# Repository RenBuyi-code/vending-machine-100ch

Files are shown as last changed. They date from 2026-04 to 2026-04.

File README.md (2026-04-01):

# Vending Machine 100-Channel Motor Driver

[!\[License\](https://img.shields.io/badge/License-Apache%202.0-blue.svg null)](LICENSE)

An open-source **100-channel vending machine motor driver control system** based on the **SWM181** microcontroller. Supports multiple motor types including spring motors, electromagnetic locks, and crawler-type motors, with RS485 communication protocol.

***

## Table of Contents

- [Overview](#overview)
- [Features](#features)
- [Hardware Architecture](#hardware-architecture)
- [Communication Protocol](#communication-protocol)
- [Project Structure](#project-structure)
- [Getting Started](#getting-started)
- [Default Configuration](#default-configuration)
- [License](#license)

***

## Overview

This project provides a complete firmware solution for controlling up to 100 motors in a vending machine setup. It uses a 10x10 matrix configuration to drive various types of motors commonly found in vending machines, including spring-based dispensers, electromagnetic locks, and crawler-type mechanisms.

The system is built around the Synwit SWM181 microcontroller (ARM Cortex-M0 core) and communicates via RS485 protocol, making it suitable for industrial vending machine applications.

***

## Features

### Motor Control

- **100-channel matrix control** (10x10 matrix, supporting up to 100 motors)
- **Multiple motor type support**:
  - Spring motors with feedback (FB Motor)
  - Electromagnetic locks with feedback (FB Electromagnet)
  - Electromagnetic locks without feedback (NFB Electromagnet)
  - Crawler-type motors with feedback (FB Crawler)

### Communication & Safety

- **RS485 communication** with dual-channel support
- **Infrared detection** for anti-pinch and goods detection
- **CRC16 checksum** for reliable communication
- **Watchdog timer** support for system stability

### Monitoring & Updates

- **Ambient monitoring** (temperature & humidity via Modbus RTU)
- **Electronic lock control**
- **XMODEM protocol** support for firmware updates

***

## Hardware Architecture

| Component | Description |
| --- | --- |
| MCU | SWM181 (ARM Cortex-M0, 48MHz) |
| Communication | RS485 (Dual Channel) |
| Motor Drive | 10x10 Matrix (X-Y control) |
| Feedback | 10-channel position feedback  |
| Sensors | Infrared detection (NPN type) |
| Power | 12V/24V DC |
| Debug | SWD/J-Link support |

### Matrix Configuration

- **X Axis (Columns)**: 10 channels for motor selection
- **Y Axis (Rows)**: 10 channels for motor activation
- **Feedback**: 10 channels for position sensing

***

## Communication Protocol

The system uses a custom frame protocol over RS485 with CRC16 error checking.

### Frame Structure

```
+------------+-------------+----------------+------+------+-----------+----------+
| Frame Head | Device Type | Device Address | CMD  | Data | CRC16     | Frame End|
| 0xDDCCBBAA | 1 byte      | 1 byte         | 1 byte| var | 2 bytes   |0xFBFCFDFE|
| (4 bytes)  |             |                |      |      |           | (4 bytes)|
+------------+-------------+----------------+------+------+-----------+----------+
```

### Supported Commands

| Command | Value  | Description |
| --- | --- | --- |
| CMD\_OUTPUT | `0x01` | Control motor to dispense goods |
| CMD\_READ | `0x02` | Read temperature, humidity, lock status |
| CMD\_LOCK | `0x03` | Control electronic lock |
| CMD\_REPLY | `0x04` | Response frame |
| CMD\_MODIFICATION | `0x05` | Modify device RS485 address |

### Response Codes

| Code | Value  | Description |
| --- | --- | --- |
| RESULT\_VM\_FB\_MOTOR\_OUTPUT | `0xC1` | Motor output result |
| RESULT\_VM\_STATES | `0xC2` | Status query result |
| RESULT\_VM\_ADDR\_MODIFICATION | `0xC3` | Address modification result |
| RESULT\_VM\_LOCK | `0xC4` | Lock control result |
| RESULT\_VM\_OUTPUT\_NFB\_ELECTROMAGNET | `0xC5` | NFB electromagnet result |
| RESULT\_VM\_OUTPUT\_FB\_ELECTROMAGNET  | `0xC6` | FB electromagnet result |

***

## Project Structure

```
vending-machine-100ch/
├── Code/
│   └── spring_drive_V1.6/          # Firmware source code (Keil MDK project)
│       ├── Application/             # Application layer
│       │   ├── main.c               # Main entry point
│       │   ├── vm.c / vm.h          # Vending machine logic & protocol
│       │   ├── ambient.c / ambient.h# Temperature & humidity monitoring
│       │   ├── xmodem.c / xmodem.h  # Firmware update protocol
│       │   ├── soft_timer.c/h       # Software timer implementation
│       │   ├── Drivers/             # Hardware drivers
│       │   │   └── Source/
│       │   │       ├── motor_driver.c   # Motor control (10x10 matrix)
│       │   │       ├── rs485.c          # RS485 communication driver
│       │   │       ├── infrared_ray_check.c  # IR sensor detection
│       │   │       ├── lock.c           # Electronic lock control
│       │   │       ├── led.c            # LED indicator control
│       │   │       ├── timer.c          # Hardware timer
│       │   │       ├── tick.c           # System tick
│       │   │       ├── uart.c           # UART driver
│       │   │       ├── address.c        # Device address management
│       │   │       └── flash.c          # Flash storage
│       │   ├── SEEGER/              # SEGGER RTT debug
│       │   └── MALLOC/              # Memory allocator
│       └── Project/                 # Keil project files
│           ├── spring.uvprojx       # Keil project
│           └── RTE/                 # Runtime environment
│
├── HW/
│   └── 弹簧货道电机驱动板V0816/      # Hardware design files
│       ├── SCH/                     # Schematics (Altium Designer)
│       ├── PCB/                     # PCB layout
│       ├── Project/                 # Altium project files
│       ├── Libraries/               # Component libraries
│       ├── Datasheet/               # Component datasheets
│       │   ├── 主控/                # MCU datasheet (SWM181)
│       │   └── 通信IC/              # Communication IC datasheets
│       └── Output/                  # Manufacturing outputs
│
└── LICENSE                          # Apache 2.0 License
```

***

## Getting Started

### Hardware Requirements

- **Vending machine motor driver board** (弹簧货道电机驱动板 V0816)
- **Power supply**: 12V/24V DC (depending on motor specifications)
- **RS485 master controller** (for communication)
- **Motors**: Spring motors, electromagnetic locks, or crawler-type motors
- **Debugger**: J-Link or compatible SWD debugger

### Software Requirements

- **Keil MDK-ARM** (version 5.0 or later recommended)
- **J-Link Software** (for debugging and flashing)
- **Serial terminal** (for RS485 communication testing)

### Build Instructions

1. **Open the project**:
   ```
   Code/spring_drive_V1.6/Project/spring.uvprojx
   ```
2. **Select target device**: SWM181xC or SWM181xB
3. **Build the project**:
   - Click `Build` button or press `F7`
4. **Connect debugger**:
   - Connect J-Link to the SWD interface on the board
5. **Flash firmware**:
   - Click `Download` button or press `F8`

### Communication Test

1. Connect RS485 to your master controller
2. Set baudrate to 115200
3. Send test frame:
   ```
   Frame Head: AA BB CC DD
   Device Type: 01
   Device Address: 01
   CMD: 02 (Read Status)
   Data: 00 00 00 00 00 00 00
   CRC16: [calculated]
   Frame End: FE FD FC FB
   ```

***

## Default Configuration

| Parameter | Default Value | Description |
| --- | --- | --- |
| RS485 Address | `0x01` | Device address (modifiable via CMD 0x05) |
| Broadcast Address | `0xFF` | Broadcast address for all devices |
| Baudrate | 115200 | RS485 communication speed |
| Device Type | `0x01` | Motor driver device type |
| Frame Head | `0xDDCCBBAA`  | Protocol frame header |
| Frame End | `0xFBFCFDFE`  | Protocol frame footer |
| Watchdog | Enabled | System watchdog timer |
| Max Channels | 100 | Maximum motor channels (10x10) |

***

## License

This project is licensed under the **Apache License 2.0**.

See [LICENSE](LICENSE) file for details.

***

## Notes

- X and Y axis mapping follows the schematic design
- Infrared sensor uses NPN signal type
- Motor feedback signals are active-low
- Ensure proper power supply current rating for all connected motors

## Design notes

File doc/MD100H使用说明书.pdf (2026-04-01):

# MD100H使用说明书

1 / 22

目录

2 / 22

3 / 22

1.版本修订

2019-2-25 全新修订 RBY

2.产品概览

- 矩阵式电路结构
- 支持100通道的电机驱动
- 支持最多255块控制卡并联扩展
- 增强型灵活通讯口，板载一路RS232,两路RS485，两路TTL其中一路复用给
RS232,RS485。
- 带一路N-MOS开关量输出可接机柜锁
- 温湿度采样，支持RS485接口的传感器级联

3.电气特性

供电电压：DC24V （12V可选）
静态电流： 小于20mA
驱动电流：最大3A
通讯接口：RS485,RS232,TTL_UART

4 / 22

## 3.1安装尺寸（mm）

X孔距115mm
Y孔距80mm
板长 124.714
板宽 88.138mm

5 / 22

4.接线方式

4.1电源接线方式

供电电压24V，12V可选
静态电流 小于40mA

最大电流取决于负载电流。

## 4.2锁接线方式

注意板子由12V供电时机柜锁7812无法输出12V，但与电源共地仍能完成锁控制 Y为输出，Y截至时为高阻态，Y导通时接地
IN用于接入机柜锁反馈线，电压不可高于3.3V。默认为3.3V，将其拉低则门状态改变。

6 / 22

4.2电机或电磁锁接线方式

X接负载正，Y接负载负，IN接负载反馈

7 / 22

4.3光栅接线方式

光幕接口 信号 V1，GND，IN V1给光幕供电，GND是电源地线，IN光栅信号 待机时，IN需要高阻抗或者0V，检测道商品掉落时为5V。

## 4.4主通信接口

2R : RS232 RX
2T : RS232 TX
UR: UART RXD
UT: UART TXD
A1: RS485 A
B1: RS485B
此通信接口用于控制整个板卡，以上3路接口不可同时使用

8 / 22

4.5传感器通信接口

5V:接传感器+
0V:接传感器-
A2: RS485 A
B2: RS485 B

# 6.通信参数

通讯参数： 9600bps，1停止位，无奇偶校验，无流量控制

在通讯过程中，上位机（安卓或者PC，称为主机）与控制卡（称为从机）采用主从方

式
1) 每次通讯由主机发起请求，从机应答
2) 主机收到上次请求的应答 或者超时后才可以发起新的请求
3) 在一个通讯网络中可包含一台主机和若干台从机
4) 地址0XFF作为广播地址。只用作从机地址修改。

通讯流程如下：
1. 主机下发指令
2. 等待50ms
3. 接收从机响应(超时8秒)

9 / 22

6.1通信格式 上位机 → 下位机

协议格式 ，PC Android或Linux主板为上位机，板卡为下位机
帧起始域(Feame Start) | 4byte
设备类型（Device_Type） | 1byte
地址域（Address） | 1byte
功能码(Funtion Code) | 1byte
数据域(Date) | 5byte
差错校验(CRC16) | 2byte
帧结束域(Feame End) | 4byte

通讯协议中使用的数据帧，一帧指令或响应的长度为18字节（数据域不足5个补0），

包含了帧头、设备类型、地址、指令、数据段、帧尾及校验码七部分。
帧起始域 | AAH | BBH | CCH | DDH
帧结束域 | FEH | FDH | FCH | FBH
设备类型 | 01H-FFH | 电机驱动板01H
地址域（普通地址） | 01H - FEH | 默认为01H
地址域（广播地址） | FFH
功能码 | 值 | 备注
CMD_OUTPUT | 01H | 驱动负载
CMD_READ | 02H | 读传感器值，以及锁状态
CMD_LOCK | 03H | 操作机柜锁
CMD_REPLY | 04H | 回复
CMD_MODIFICATION_ADDRES S | 05H | 修改地址

10 / 22

## 6.2 CMD_OUTPUT 数据域

名称 | 位 | 类型 | 数据类型 | 描述
load_number | Byte1 | R/W | uint8_t | 负载编号，取值01H-64H
load_flag | Byte2 | R | uint8_t | 负载标志 下位机->上位机: 正常：01H 错误：EEH 超时：00H
ir_flag | Byte3 | R/W | uint8_t | 红外标志位 上位机->下位机: 使能掉货检测：FFH 失能掉货检测：EFH 下位机->上位机： 正常：01H 错误：EEH 超时：00H
load_type | Byte4 | W | uint8_t | 负载类型: 有反馈弹簧电机：00H 有反馈电磁锁：01H 无反馈电磁锁：02H 有反馈履带电机：0x03
timer_value | Byte5 | W | uint8_t | 超时定时器单位为秒

## 6.3 CMD_READ 数据域

上位机->下位机，数据域全部补0。

## 6.4 CMD_LOCK 数据域

名称 | 类型 | 数据类型 | 描述
states | R/W | uint8_t | 0x01锁负极接地， 0x00锁负极高阻

11 / 22

## 6.5 CMD_REPLY 数据域

上位机->下位机此域无效

## 6.6 CMD_MODIFICATION_ADDRESS 数据域

名称 | 类型 | 数据类型 | 描述
new_address | R/W | uint8_t | 取值为00H-FEH

默认地址为01H
7.通信格式 下位机 → 上位机

回复时功能码皆为04H，即CMD_REPLY

## 7.1 CMD_OUTPUT回复

数据域

名称 | 位 | 类型 | 数据类型 | 描述
load_number | 1 | R/W | uint8_t | 负载编号:01H-64H
load_flag | 2 | R/W | uint8_t | 正常 : 01H 超时 : 00H 出错 : EEH
ir_flag | 3 | R/W | uint8_t | 正常 : 01H 超时 : 00H 出错 : EEH

12 / 22

## 7.2 CMD_READ 回复

数据域
名称 | 位 | 类型 | 数据类型 | 描述
lock_states | 1 | R/W | uint8_t | 导通0xFF, 截至0x00
humidity | 2:3 | R/W | short | 湿度，小端字节序
temperature | 4:5 | R/W | short | 温度，小端字节序

操作锁，电机，查询修改地址都会有回复。

13 / 22

### 7.3 板卡通信例子

7.3.1控制板卡驱动负载，失能光栅。

上位机->下位机

例子：控制板卡地址01H和01H号负载，不检测光栅。
AA BB CC DD 01 01 01 01 00 EF 00 00 06 24 FE FD FC FB
AA BB CC DD 01 01 01 01 00 EF 00 00 06 24 FE FD FC FB
名称 | 字节域&描述 | 值
帧起始域 | 1 | AAH
| 2 | BBH
| 3 | CCH
| 4 | DDH
设备类型 | 5 | 01H
地址域 | 6 地址 | 01H
功能码 | 7 功能码 | 01H
数据域 | 8 负载编号 | 01H
| 9 负载标志 | 00H
| 10 光栅标志 | EFH
| 11 无效字节 | 00H
| 12 无效字节 | 00H
差错校验 CRC16_Modbus | 13 低位 | 06H
| 14 高位 | 24H
帧结束域 | 15 | FEH
| 16 | FDH
| 17 | FCH
| 18 | FBH

14 / 22

下位机->上位机

例子：不检测光栅EFH，负载标志01表示电机正常旋转一周。
AA BB CC DD 01 04 01 01 EF 00 00 11 B2 FE FD FC FB
名称 | 字节域&描述 | 值
帧起始域 | 1 | AAH
| 2 | BBH
| 3 | CCH
| 4 | DDH
设备类型 | 5 售货机类型 | 01H
地址域 | 6 地址 | 01H
功能码 | 7 功能码 | 04H
数据域 | 8 负载编号 | 01H
| 9 负载标志 | 01H
| 10 光栅标志 | EFH
| 11 无效 | 00H
| 12 无效 | 00H
差错校验 CRC16_Modbus | 13 低位 | 11H
| 14 高位 | B2H
帧结束域 | 15 | FEH
| 16 | FDH
| 17 | FCH
| 18 | FBH

15 / 22

7.3.2控制板卡驱动负载，使能光栅检测

上位机->下位机

例子：控制板卡地址01H和01H号负载，检测光栅。
AA BB CC DD 01 01 01 00 FF 00 00 07 E1 fe fd fc fb
名称 | 字节域&描述 | 值
帧起始域 | 1 | AAH
| 2 | BBH
| 3 | CCH
| 4 | DDH
设备类型 | 5 售货机类型 | 01H
地址域 | 6 地址 | 01H
功能码 | 7 功能码 | 01H
数据域 | 8 负载编号 | 01H
| 9 负载表示 | 00H
| 10 光栅标志 | FFH
| 11 无效 | 00H
| 12 无效 | 00H
差错校验 CRC16_Modbus | 13 低位 | 07H
| 14 高位 | E1H
帧结束域 | 15 | FEH
| 16 | FDH
| 17 | FCH
| 18 | FBH

16 / 22

下位机->上位机

例子：控制板卡地址01H和01H号负载，使能检测光栅。
AA BB CC DD 01 01 01 04 01 11 EE 00 00 01 72 FE FD FC FB
名称 | 字节域&描述 | 值
帧起始域 | 1 | AAH
| 2 | BBH
| 3 | CCH
| 4 | DDH
设备类型 | 5 售货机类型 | 01H
地址域 | 6 地址 | 01H
功能码 | 7 功能码 | 04H
数据域 | 8 负载编号 | 01H
| 9 负载表示 | 11H
| 10 光栅标志 | EEH
| 11 无效 | 00H
| 12 无效 | 00H
差错校验 CRC16_Modbus | 13 低位 | 01H
| 14 高位 | 72H
帧结束域 | 15 | FEH
| 16 | FDH
| 17 | FCH
| 18 | FBH

17 / 22

7.3.3查询温湿度传感器及锁状态

上位机->下位机

AA BB CC DD 01 01 02 00 00 00 00 00 0A 22 FE FD FC FB
名称 | 字节域&描述 | 值
帧起始域 | 1 | AAH
| 2 | BBH
| 3 | CCH
| 4 | DDH
设备类型 | 5 售货机类型 | 01H
地址域 | 6 地址 | 01H
功能码 | 7 功能码 | 02H
数据域 | 8 锁状态 | 00H
| 9 湿度低 | 00H
| 10 湿度高 | 00H
| 11 温度低 | 00H
| 12 温度高 | 00H
差错校验 CRC16_Modbus | 13 低位 | 0AH
| 14 高位 | 22H
帧结束域 | 15 | FEH
| 16 | FDH
| 17 | FCH
| 18 | FBH

18 / 22

下位机->上位机

名称 | 字节域&描述 | 值
帧起始域 | 1 | AAH
| 2 | BBH
| 3 | CCH
| 4 | DDH
设备类型 | 5 售货机类型 | 01H
地址域 | 6 地址 | 01H
功能码 | 7 功能码 | 02H
数据域 | 8 锁状态 | 00H
| 9 湿度低 | 00H
| 10 湿度高 | 00H
| 11 温度低 | 00H
| 12 温度高 | 00H
差错校验 CRC16_Modbus | 13 低位 | 0AH
| 14 高位 | 22H
帧结束域 | 15 | FEH
| 16 | FDH
| 17 | FCH
| 18 | FBH

AA BB CC DD 01 04 00 04 02 24 00 E6 FB FE FD FC FB
备注：锁闭合时，信号线导通Byte.7=00H,锁打开时Byte.7=01H，使用时注意电锁有无反馈

功能，反馈形式应为，锁闭合反馈线导通，锁打开是，反馈线开路。

19 / 22

### 7.3.4 控制板卡开关机柜锁

上位机->下位机

AA BB CC DD 01 03 01 00 00 00 00 36 33 FE FD FC FB

名称 | 字节域&描述 | 值
帧起始域 | Byte.1 | AAH
| Byte.2 | BBH
| Byte.3 | CCH
| Byte.4 | DDH
地址域 | Byte.5 地址 | 01H
功能码 | Byte.6 功能码 | 03H
数据域 | Byte.7 锁状态 | 00H
| Byte.8 湿度低 | 00H
| Byte.9 湿度高 | 00H
| Byte.10 温度低 | 00H
| Byte.11 温度高 | 00H
差错校验 CRC16_Modbus | Byte.12 低位 | 36H
| Byte.13 高位 | 33H
帧结束域 | Byte.14 | FEH
| Byte.15 | FDH
| Byte.16 | FCH
| Byte.17 | FBH
备注:
默认为开锁3S后，关闭锁，注意锁可以导通的时间。

下位机->上位机

与 7.3.3 下位机->上位机 相同

20 / 22

7.3.5修改板卡地址

上位机->下位机

AA BB CC DD 01 05 02 00 00 00 00 72 55 FE FD FC FB
名称 | 字节域&描述 | 值
帧起始域 | 1 | AAH
| 2 | BBH
| 3 | CCH
| 4 | DDH
设备类型 | 5 | 01H
地址域 | 5 地址 | 01H
功能码 | 6 功能码 | 05H
数据域 | 7 新地址 | 01H
| 8 无效 | 00H
| 9 无效 | 00H
| 10 无效 | 00H
| 11 无效 | 00H
差错校验 CRC16_Modbus | 12 低位 | 72H
| 13 高位 | 55H
帧结束域 | 14 | FEH
| 15 | FDH
| 16 | FCH
| 17 | FBH

备注：
此命令将板卡地址01H,改为02H,修改成功则会回复7.3.3下位机->上位机,注意板卡地址 会是否改为02H，如果是则修改成功。

21 / 22

### 8. 校验码计算

红字为参与校验的数据
帧起始域(Feame Start) | 4byte
设备类型（Device_Type） | 1byte
地址域（Address） | 1byte
功能码(Funtion Code) | 1byte
数据域(Date) | 5byte
差错校验(CRC16) | 2byte
帧结束域(Feame End) | 4byte
const uint8_t crctalbeabs[23] = { 0x7E, 0x01, 0x00, 0x00, 0x01, 0x10, 0x02, 0x00, 0x27, 0x00, 0x 0C, 0x00, 0x02, 0x00, 0x00, 0x00, 0x00, 0x00, 0x50, 0x00, 0x3C, 0x00, 0x03};
uint16_t crc16tablefast(uint8_t *ptr, uint16_t len)
{
unsigned char i;
unsigned short crc = 0xFFFF;
if (len == 0) {
len = 1;
}
while (len--) {
crc ^= *ptr;
for (i = 0; i<8; i++)
{
if (crc & 1) {
crc >>= 1;
crc ^= 0xA001;
} else {
crc >>= 1;
}
}
ptr++;
}
return crc;
}

备注：注意字节序问题

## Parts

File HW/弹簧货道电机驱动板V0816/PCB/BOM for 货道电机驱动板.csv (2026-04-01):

Comment | Description | Designator | Footprint | LibRef | Pins | Quantity
0R | 贴片电阻 | R25 | R 0603 | R | 2 | 1
100nF\NC | 贴片电容 | C12,C11,C10,C9,C8 | 0603_C | 0603 100nF (104) 10% 50V | 2 | 5
104 | 无极性贴片电容 | C3,C4,C2,C6,C1,C16,C13,C7 | C 0603 | C | 2 | 8
10K | 贴片电阻 | R24,R14,R9,R21,R11_U_SIG_IN10,R11_U_SIG_IN9,R11_U_SIG_IN8,R11_U_SIG_IN7,R11_U_SIG_IN6,R11_U_SIG_IN5,R11_U_SIG_IN4,R11_U_SIG_IN3,R11_U_SIG_IN2,R11_U_SIG_IN1,R7_U_Drive_Y10,R7_U_Drive_Y9,R7_U_Drive_Y8,R7_U_Drive_Y7,R7_U_Drive_Y6,R7_U_Drive_Y5,R7_U_Drive_Y4,R7_U_Drive_Y3,R7_U_Drive_Y2,R7_U_Drive_Y1,R4_U_Drive_X10,R4_U_Drive_X9,R4_U_Drive_X8,R4_U_Drive_X7,R4_U_Drive_X6,R4_U_Drive_X5,R4_U_Drive_X4,R4_U_Drive_X3,R4_U_Drive_X2,R4_U_Drive_X1,R1_U_Drive_X10,R1_U_Drive_X9,R1_U_Drive_X8,R1_U_Drive_X7,R1_U_Drive_X6,R1_U_Drive_X5,R1_U_Drive_X4,R1_U_Drive_X3,R1_U_Drive_X2,R1_U_Drive_X1 | R 0603 | R | 2 | 44
10k | 贴片电阻 | R5_U_Drive_Y10,R5_U_Drive_Y9,R5_U_Drive_Y8,R5_U_Drive_Y7,R5_U_Drive_Y6,R5_U_Drive_Y5,R5_U_Drive_Y4,R5_U_Drive_Y3,R5_U_Drive_Y2,R5_U_Drive_Y1 | R 0603 | R | 2 | 10
10uF/35V | 贴片电解电容 | E3,E4 | CM B(4*5.4) | C-CM | 2 | 2
120Ω | 贴片电阻 | R15 | 0603_R | 0603 120Ω (1200) 1% | 2 | 1
15K | 贴片电阻 | R17,R2_U_Drive_X10,R2_U_Drive_X9,R2_U_Drive_X8,R2_U_Drive_X7,R2_U_Drive_X6,R2_U_Drive_X5,R2_U_Drive_X4,R2_U_Drive_X3,R2_U_Drive_X2,R2_U_Drive_X1 | R 0603 | R | 2 | 11
1K | 贴片电阻 | R23,R22,R20,R6_U_Drive_Y10,R6_U_Drive_Y9,R6_U_Drive_Y8,R6_U_Drive_Y7,R6_U_Drive_Y6,R6_U_Drive_Y5,R6_U_Drive_Y4,R6_U_Drive_Y3,R6_U_Drive_Y2,R6_U_Drive_Y1,R3_U_Drive_X10,R3_U_Drive_X9,R3_U_Drive_X8,R3_U_Drive_X7,R3_U_Drive_X6,R3_U_Drive_X5,R3_U_Drive_X4,R3_U_Drive_X3,R3_U_Drive_X2,R3_U_Drive_X1 | R 0603 | R | 2 | 23
20pF | 无极性贴片电容 | C14,C5 | C 0603 | C | 2 | 2
220uF/35V | 贴片电解电容 | E6,E2 | CM E(8*10.2) | C-CM | 2 | 2
24MHz | 2脚晶振 | X1 | XTAL-49S SMD | XTAL-2 | 2 | 1
4.7K | 贴片电阻 | R8,R19,R12,R16,R18,R13,R10_U_SIG_IN10,R10_U_SIG_IN9,R10_U_SIG_IN8,R10_U_SIG_IN7,R10_U_SIG_IN6,R10_U_SIG_IN5,R10_U_SIG_IN4,R10_U_SIG_IN3,R10_U_SIG_IN2,R10_U_SIG_IN1 | R 0603 | R | 2 | 16
47uF/6.3V | 贴片电解电容 | E5 | CM C(5*5.4) | C-CM | 2 | 1
680uF/6.3V | 贴片电解电容 | E1 | CM E(8*10.2) | C-CM | 2 | 1
68uH 2A | INDUCTOR | L1 | CDRH74 | INDUCTOR | 2 | 1
78Mxx | 线性稳压芯片 | V1 | LC-TO-252-2 | 78Mxx | 3 | 1
AMS1117-3.3 | 低压差线性稳压(LDO) | VR1 | SOT-223 | SOT-223 AMS1117-3.3 | 4 | 1
CJ2307 | P沟道场效应管 | Q8 | SOT23 | P-MOS | 3 | 1
CJA03N10 | N沟道场效应管 | Q6 | LC-SOT-89(SOT-89-3) | CJA03N10 | 4 | 1
HD30N03 | N沟道场效应管 | Q4_U_Drive_Y10,Q4_U_Drive_Y9,Q4_U_Drive_Y8,Q4_U_Drive_Y7,Q4_U_Drive_Y6,Q4_U_Drive_Y5,Q4_U_Drive_Y4,Q4_U_Drive_Y3,Q4_U_Drive_Y2,Q4_U_Drive_Y1 | TO252 | N-MOS | 3 | 10
HDR-1X2 | 2P接插件 | JP11 | HDR-1X2 | Header 2 | 2 | 1
HDR-1X4 | 4P接插件 | JP6 | HDR-1X4 | Header 4 | 4 | 1
HDR-1X4 | 4P接插件 | JP9 | XH2.54-4P | Header 4 | 4 | 1
S8050 | NPN三极管 | Q9,Q7,Q5_U_SIG_IN10,Q5_U_SIG_IN9,Q5_U_SIG_IN8,Q5_U_SIG_IN7,Q5_U_SIG_IN6,Q5_U_SIG_IN5,Q5_U_SIG_IN4,Q5_U_SIG_IN3,Q5_U_SIG_IN2,Q5_U_SIG_IN1,Q3_U_Drive_Y10,Q3_U_Drive_Y9,Q3_U_Drive_Y8,Q3_U_Drive_Y7,Q3_U_Drive_Y6,Q3_U_Drive_Y5,Q3_U_Drive_Y4,Q3_U_Drive_Y3,Q3_U_Drive_Y2,Q3_U_Drive_Y1,Q2_U_Drive_X10,Q2_U_Drive_X9,Q2_U_Drive_X8,Q2_U_Drive_X7,Q2_U_Drive_X6,Q2_U_Drive_X5,Q2_U_Drive_X4,Q2_U_Drive_X3,Q2_U_Drive_X2,Q2_U_Drive_X1 | SOT-23 | NPN | 3 | 32
SE20P03 | P沟道场效应管 | Q1_U_Drive_X10,Q1_U_Drive_X9,Q1_U_Drive_X8,Q1_U_Drive_X7,Q1_U_Drive_X6,Q1_U_Drive_X5,Q1_U_Drive_X4,Q1_U_Drive_X3,Q1_U_Drive_X2,Q1_U_Drive_X1 | TO252 | P-MOS | 3 | 10
SMAJ6.5CA | TVS | D6,D8,D10,D5 | SMA(DO-214AC)_S1 | SMB/DO-214AA P6SMB6.8CA | 2 | 4
SMBJ30CA | TVS | D9,D2 | LC-SMA(DO-214AC)_S1 | SMB/DO-214AA P6SMB6.8CA | 2 | 2
SS34 | 二极管 | D3,D7,D4,D1 | SMA(DO-214AC)_S1 | SMA(DO-214AC) SS54 | 2 | 4
SWM181RCT6-50 | 微控制器, Cortex-M0系列, AA-00 | U1 | LC-LQFP-64_10x10x05P | SWM181RCT6-50 | 64 | 1
TLC-NSMD005 | 贴片保险丝 | F3,F2 | FU 1206 | FU | 2 | 2
TRB300 | 直插保险丝 | F1 | 5.08mm | FU | 2 | 1
UT3232G-S16-R | RS232 | U4 | SOIC-16_150mil | MAX232ESE | 16 | 1
XH2.54-10P | 10P接插件 | JP3,JP2 | XH2.54-10P | Header 10 | 10 | 2
XH2.54-11P | 11P接插件 | JP5 | XH2.54-11P | Header 11 | 11 | 1
XH-2.54-4P | 4P接插件 | JP10,JP8,JP4,JP1 | XH2.54-4P | Header 4 | 4 | 4
XH-2.54-8P | 8P接插件 | JP7 | XH2.54-8P | Header 8 | 8 | 1
XL1509-5E1 | DC-DC芯片 | U2 | SOP-8_150mil | XL1509-3.3E1 | 8 | 1
YD3082E | RS-485/RS-422 | U5,U3 | SOIC-8_150mil | SP485EEN-L/TR | 8 | 2
红色 | 贴片LED | LED1 | LED 0603G | LED-SMD | 2 | 1

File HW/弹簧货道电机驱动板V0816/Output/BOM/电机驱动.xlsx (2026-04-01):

Comment | Description | Designator | Footprint | Pins | Quantity
24MHz | 2脚晶振 | X1 | XTAL-49S SMD | 2 | 1
XL1509-5E1 | DC-DC芯片 | U2 | SOP-8_150mil | 8 | 1
SWM181RCT6-50 | 微控制器, Cortex-M0系列, AA-00 | U1 | LC-LQFP-64_10x10x05P | 64 | 1
AMS1117-3.3 | 低压差线性稳压(LDO) | VR1 | SOT-223 | 3 | 1
SMAJ3.3A | TVS | D11 | LC-SMA(DO-214AC)_S1 | 2 | 1
SMAJ6.5CA | TVS | D5, D6, D8, D10 | SMA(DO-214AC)_S1 | 2 | 4
SMBJ30CA | TVS | D2, D9 | LC-SMA(DO-214AC)_S1 | 2 | 2
SS34 | 二极管 | D1, D3, D4, D7 | SMA(DO-214AC)_S1 | 2 | 4
1K | 贴片电阻 | R3_U_Drive_X1, R3_U_Drive_X2, R3_U_Drive_X3, R3_U_Drive_X4, R3_U_Drive_X5, R3_U_Drive_X6, R3_U_Drive_X7, R3_U_Drive_X8, R3_U_Drive_X9, R3_U_Drive_X10, R6_U_Drive_Y1, R6_U_Drive_Y2, R6_U_Drive_Y3, R6_U_Drive_Y4, R6_U_Drive_Y5, R6_U_Drive_Y6, R6_U_Drive_Y7, R6_U_Drive_Y8, R6_U_Drive_Y9, R6_U_Drive_Y10, R20, R22 | R 0603 | 2 | 22
4.7K | 贴片电阻 | R8, R9, R10_U_SIG_IN1, R10_U_SIG_IN2, R10_U_SIG_IN3, R10_U_SIG_IN4, R10_U_SIG_IN5, R10_U_SIG_IN6, R10_U_SIG_IN7, R10_U_SIG_IN8, R10_U_SIG_IN9, R10_U_SIG_IN10, R12, R13, R16, R18, R19 | R 0603 | 2 | 17
10K | 贴片电阻 | R1_U_Drive_X1, R1_U_Drive_X2, R1_U_Drive_X3, R1_U_Drive_X4, R1_U_Drive_X5, R1_U_Drive_X6, R1_U_Drive_X7, R1_U_Drive_X8, R1_U_Drive_X9, R1_U_Drive_X10, R4_U_Drive_X1, R4_U_Drive_X2, R4_U_Drive_X3, R4_U_Drive_X4, R4_U_Drive_X5, R4_U_Drive_X6, R4_U_Drive_X7, R4_U_Drive_X8, R4_U_Drive_X9, R4_U_Drive_X10, R5_U_Drive_Y1, R5_U_Drive_Y2, R5_U_Drive_Y3, R5_U_Drive_Y4, R5_U_Drive_Y5, R5_U_Drive_Y6, R5_U_Drive_Y7, R5_U_Drive_Y8, R5_U_Drive_Y9, R5_U_Drive_Y10, R7_U_Drive_Y1, R7_U_Drive_Y2, R7_U_Drive_Y3, R7_U_Drive_Y4, R7_U_Drive_Y5, R7_U_Drive_Y6, R7_U_Drive_Y7, R7_U_Drive_Y8, R7_U_Drive_Y9, R7_U_Drive_Y10, R11_U_SIG_IN1, R11_U_SIG_IN2, R11_U_SIG_IN3, R11_U_SIG_IN4, R11_U_SIG_IN5, R11_U_SIG_IN6, R11_U_SIG_IN7, R11_U_SIG_IN8, R11_U_SIG_IN9, R11_U_SIG_IN10, R14, R17 | R 0603 | 2 | 52
15K | 贴片电阻 | R2_U_Drive_X1, R2_U_Drive_X2, R2_U_Drive_X3, R2_U_Drive_X4, R2_U_Drive_X5, R2_U_Drive_X6, R2_U_Drive_X7, R2_U_Drive_X8, R2_U_Drive_X9, R2_U_Drive_X10 | R 0603 | 2 | 10
100K | 贴片电阻 | R21 | R 0603 | 2 | 1
SE20P03 | P沟道场效应管 | Q1_U_Drive_X1, Q1_U_Drive_X2, Q1_U_Drive_X3, Q1_U_Drive_X4, Q1_U_Drive_X5, Q1_U_Drive_X6, Q1_U_Drive_X7, Q1_U_Drive_X8, Q1_U_Drive_X9, Q1_U_Drive_X10 | TO252 | 3 | 10
S8550 | NPN三极管 | Q2_U_Drive_X1, Q2_U_Drive_X2, Q2_U_Drive_X3, Q2_U_Drive_X4, Q2_U_Drive_X5, Q2_U_Drive_X6, Q2_U_Drive_X7, Q2_U_Drive_X8, Q2_U_Drive_X9, Q2_U_Drive_X10, Q3_U_Drive_Y1, Q3_U_Drive_Y2, Q3_U_Drive_Y3, Q3_U_Drive_Y4, Q3_U_Drive_Y5, Q3_U_Drive_Y6, Q3_U_Drive_Y7, Q3_U_Drive_Y8, Q3_U_Drive_Y9, Q3_U_Drive_Y10, Q5_U_SIG_IN1, Q5_U_SIG_IN2, Q5_U_SIG_IN3, Q5_U_SIG_IN4, Q5_U_SIG_IN5, Q5_U_SIG_IN6, Q5_U_SIG_IN7, Q5_U_SIG_IN8, Q5_U_SIG_IN9, Q5_U_SIG_IN10 | SOT-23 | 3 | 30
2N7002 | N沟道场效应管 | Q7 | SOT23 | 3 | 1
HD30N03 | N沟道场效应管 | Q4_U_Drive_Y1, Q4_U_Drive_Y2, Q4_U_Drive_Y3, Q4_U_Drive_Y4, Q4_U_Drive_Y5, Q4_U_Drive_Y6, Q4_U_Drive_Y7, Q4_U_Drive_Y8, Q4_U_Drive_Y9, Q4_U_Drive_Y10 | TO252 | 3 | 10
红色 | 贴片LED | LED1 | LED 0603G | 2 | 1
68uH 2A | INDUCTOR | L1 | CDRH74 | 2 | 1
XH2.54-11P | 11P接插件 | JP5 | XH2.54-11P | 11 | 1
XH2.54-10P | 10P接插件 | JP2, JP3 | XH2.54-10P | 10 | 2
XH-2.54-8P | 8P接插件 | JP7 | XH2.54-8P | 8 | 1
XH-2.54-5P | 5P接插件 | JP9 | XH2.54-5P | 5 | 1
HDR-1X4 | 4P接插件 | JP6 | HDR-1X4 | 4 | 1
XH-2.54-4P | 4P接插件 | JP1, JP4, JP8, JP10 | XH2.54-4P | 4 | 4
TRB300 | 直插保险丝 | F1 | 5.08mm | 2 | 1
TLC-NSMD005 | 贴片保险丝 | F2, F3 | FU 1206 | 2 | 2
CJA03N10 | N沟道场效应管 | Q6 | LC-SOT-89(SOT-89-3) | 3 | 1
10uF/35V | 贴片电解电容 | E3, E4 | CM B(4*5.4) | 2 | 2
47uF/6.3V | 贴片电解电容 | E5 | CM C(5*5.4) | 2 | 1
220uF/35V | 贴片电解电容 | E2, E6 | CM E(8*10.2) | 2 | 2
680uF/6.3V | 贴片电解电容 | E1 | CM E(8*10.2) | 2 | 1
20pF | 无极性贴片电容 | C5, C14 | C 0603 | 2 | 2
104 | 无极性贴片电容 | C1, C2, C4, C6, C7, C13, C16 | C 0603 | 2 | 7
120Ω | 贴片电阻 | R15 | 0603_R | 2 | 1

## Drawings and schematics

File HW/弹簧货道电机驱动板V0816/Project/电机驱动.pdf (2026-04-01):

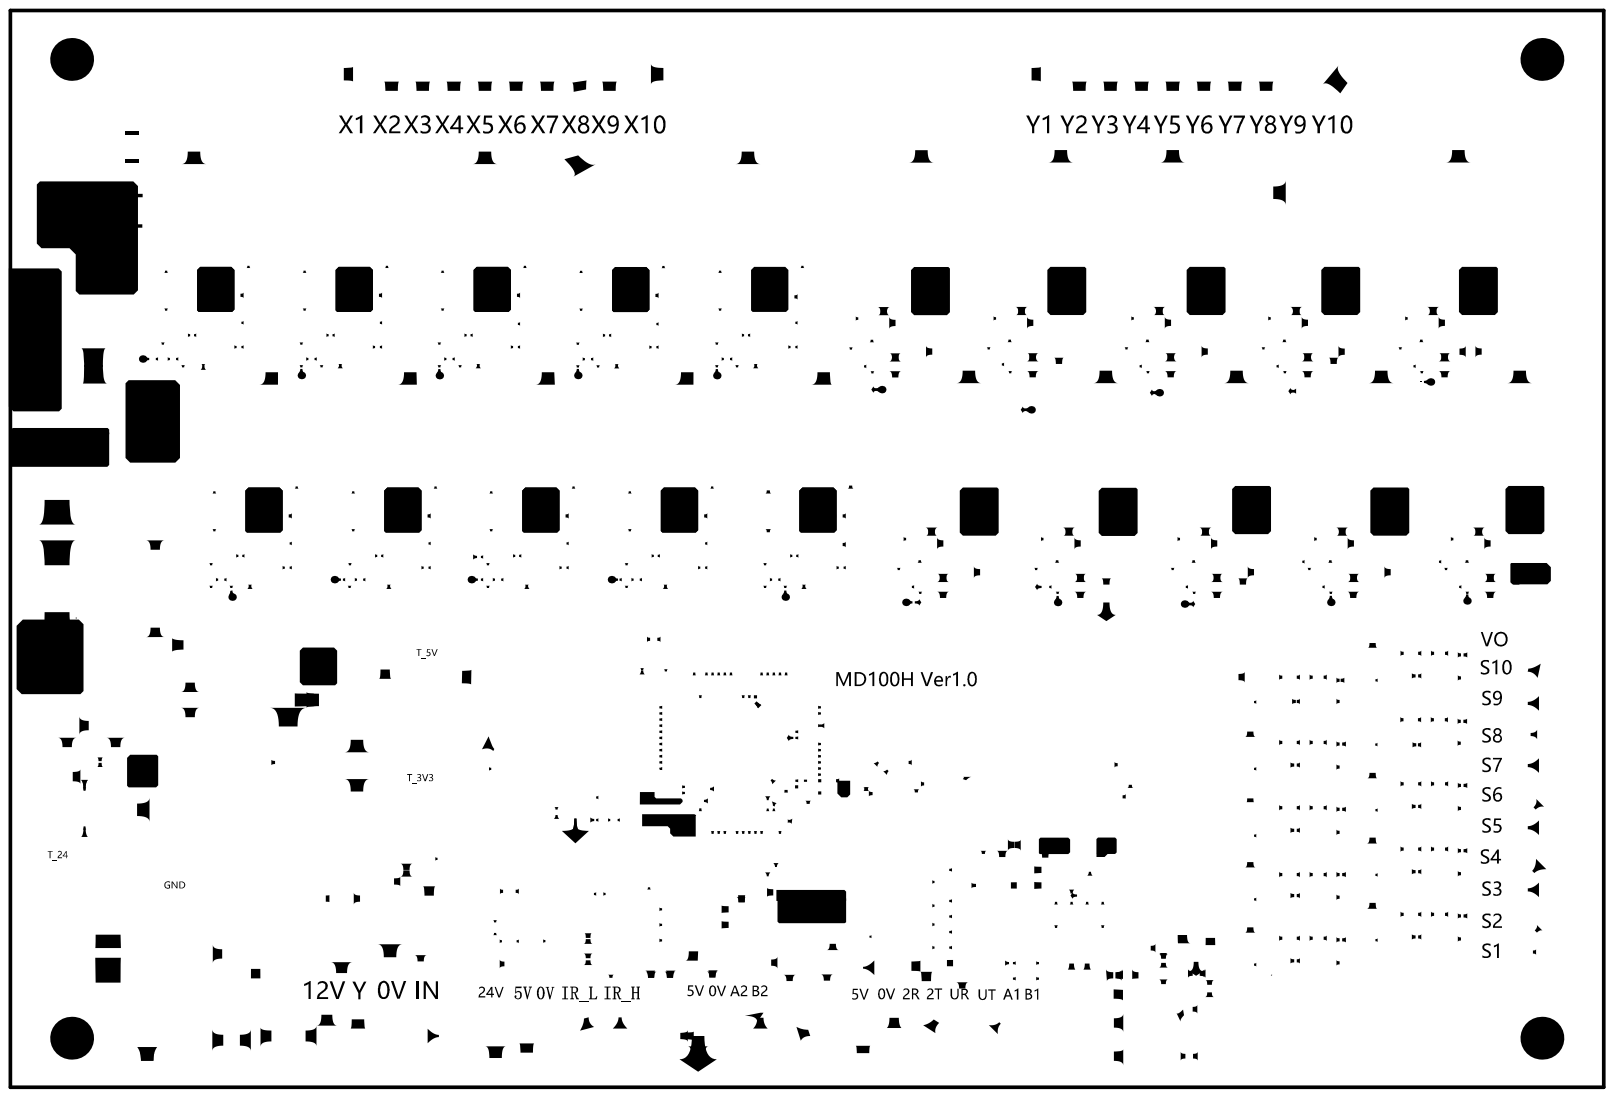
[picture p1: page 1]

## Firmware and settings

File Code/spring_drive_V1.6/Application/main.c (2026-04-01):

#include "driver_config.h"

#include "SEGGER_RTT.h"

static VM_Data_Frame vm_data_hello;

static void board_init(void)
{

    SystemInit();            //系统时钟初始化
    drive_address_config();  //初   始化设备地址
    led_init();              //初始化LED
    ir_check_init();         //光栅检测
    motor_init();            //电机引脚初始化
    rs485_channel1_config(); //rs485 通道1初始化
    rs485_channel2_config(); //rs485 通道2初始化
    lock_io_Init();          //锁控制引脚初始化
    system_tick_init();      //SysTick	初始化
    SEGGER_RTT_Init();
    __is_ask = TRUE; //开机先问一下
    ask_ambient();   //环境量

    frame_default(&vm_data_hello);
    vm_data_hello.cmd = 0XCD;

    write_frame_checkcode(&vm_data_hello);                         //写入校验码
    rs485_channel1_send((uint8_t *)&vm_data_hello, VM_Frame_SIZE); //向上位机问好
    SEGGER_RTT_printf(0, "Hi!\r\n");

#if ENABLE_WDT > 0u
    WDT_Init(WDT, SystemCoreClock * 6, WDT_MODE_RESET); //每5秒需要喂狗一次
    WDT_Start(WDT);
#endif
}

int main(void)
{
    uint16_t cnt = 0;
    board_init();

    while (TRUE == TRUE)
    {
        switch (cnt)
        {
        case 1:
        {
#if ENABLE_WDT > 0u
            WDT_Feed(WDT);
#endif
        }
        break;

        case 2:
        {
            rs485_ch1_recv();
#if ENABLE_WDT > 0u
            WDT_Feed(WDT);
#endif
        }
        break;

        case 3:
        {
            rs485_ch1_reply();
#if ENABLE_WDT > 0u
            WDT_Feed(WDT);
#endif
        }
        break;

        case 4:
        {
            ask_ambient(); //询问环境传感器
#if ENABLE_WDT > 0u
            WDT_Feed(WDT);
#endif
        }
        break;

        case 5:
        {
            rs485_ch2_recv();
#if ENABLE_WDT > 0u
            WDT_Feed(WDT);
#endif
        }
        break;
        case 6:
        {
            if (led_tick >= 7) //700MS 闪灯
            {
                LED_INV();
                led_tick = 0;
            }
        }

        default:
            cnt = 0;
            break;
        }
        cnt++;
    }
}

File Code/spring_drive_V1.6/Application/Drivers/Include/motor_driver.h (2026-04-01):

#ifndef _MOTOR_DRIVER_H
#define _MOTOR_DRIVER_H

#include "driver_config.h"
#define WM   0		//微米
#define XSC	 0  	//新视窗
#define DEFAULT 0 //默认
#define REVERSE_ORDER 1 //倒序
/**  行引脚定义 **/
#if  WM>0ul							//微米

#define DRIVER_X10_PART   GPIOB
#define DRIVER_X10_PIN		PIN6

#define DRIVER_X9_PART		GPIOB
#define DRIVER_X9_PIN			PIN7

#define DRIVER_X8_PART		GPIOB
#define DRIVER_X8_PIN			PIN8

#define DRIVER_X7_PART		GPIOB
#define DRIVER_X7_PIN			PIN9

#define DRIVER_X6_PART		GPIOB	
#define DRIVER_X6_PIN			PIN10

#define DRIVER_X5_PART		GPIOB
#define DRIVER_X5_PIN			PIN11

#define DRIVER_X4_PART		GPIOB
#define DRIVER_X4_PIN			PIN12

#define DRIVER_X3_PART		GPIOB
#define DRIVER_X3_PIN			PIN13

#define DRIVER_X2_PART		GPIOB
#define DRIVER_X2_PIN			PIN14

#define DRIVER_X1_PART		GPIOB
#define DRIVER_X1_PIN			PIN15

#endif

#if  XSC>0ul						//新视窗

#define DRIVER_X10_PART   GPIOB
#define DRIVER_X10_PIN		PIN6

#define DRIVER_X9_PART		GPIOB
#define DRIVER_X9_PIN			PIN7

#define DRIVER_X8_PART		GPIOB
#define DRIVER_X8_PIN			PIN8

#define DRIVER_X7_PART		GPIOB
#define DRIVER_X7_PIN			PIN9

#define DRIVER_X6_PART		GPIOB	
#define DRIVER_X6_PIN			PIN10

#define DRIVER_X5_PART		GPIOB
#define DRIVER_X5_PIN			PIN11

#define DRIVER_X4_PART		GPIOB
#define DRIVER_X4_PIN			PIN12

#define DRIVER_X3_PART		GPIOB
#define DRIVER_X3_PIN			PIN13

#define DRIVER_X2_PART		GPIOB
#define DRIVER_X2_PIN			PIN14

#define DRIVER_X1_PART		GPIOB
#define DRIVER_X1_PIN			PIN15

#endif


#if  DEFAULT>0ul				//默认
#define DRIVER_X10_PART   GPIOB
#define DRIVER_X10_PIN		PIN15

#define DRIVER_X9_PART		GPIOB
#define DRIVER_X9_PIN			PIN14

#define DRIVER_X8_PART		GPIOB
#define DRIVER_X8_PIN			PIN13

#define DRIVER_X7_PART		GPIOB
#define DRIVER_X7_PIN			PIN12

#define DRIVER_X6_PART		GPIOB	
#define DRIVER_X6_PIN			PIN11

#define DRIVER_X5_PART		GPIOB
#define DRIVER_X5_PIN			PIN10

#define DRIVER_X4_PART		GPIOB
#define DRIVER_X4_PIN			PIN9

#define DRIVER_X3_PART		GPIOB
#define DRIVER_X3_PIN			PIN8

#define DRIVER_X2_PART		GPIOB
#define DRIVER_X2_PIN			PIN7

#define DRIVER_X1_PART		GPIOB
#define DRIVER_X1_PIN			PIN6
#endif

#if  REVERSE_ORDER>0ul	//倒序

#define DRIVER_X10_PART   GPIOB
#define DRIVER_X10_PIN		PIN6

#define DRIVER_X9_PART		GPIOB
#define DRIVER_X9_PIN			PIN7

#define DRIVER_X8_PART		GPIOB
#define DRIVER_X8_PIN			PIN8

#define DRIVER_X7_PART		GPIOB
#define DRIVER_X7_PIN			PIN9

#define DRIVER_X6_PART		GPIOB	
#define DRIVER_X6_PIN			PIN10

#define DRIVER_X5_PART		GPIOB
#define DRIVER_X5_PIN			PIN11

#define DRIVER_X4_PART		GPIOB
#define DRIVER_X4_PIN			PIN12

#define DRIVER_X3_PART		GPIOB
#define DRIVER_X3_PIN			PIN13

#define DRIVER_X2_PART		GPIOB
#define DRIVER_X2_PIN			PIN14

#define DRIVER_X1_PART		GPIOB
#define DRIVER_X1_PIN			PIN15

#endif


/**  行引脚定义 **/


/**  列引脚定义 **/
//WM55	
#if WM>0ul							//微米

#define DRIVER_Y10_PART		GPIOD	
#define DRIVER_Y10_PIN		PIN6

#define DRIVER_Y9_PART		GPIOD	
#define DRIVER_Y9_PIN			PIN5

#define DRIVER_Y8_PART		GPIOD
#define DRIVER_Y8_PIN			PIN4

#define DRIVER_Y7_PART		GPIOD
#define DRIVER_Y7_PIN			PIN3

#define DRIVER_Y6_PART		GPIOD
#define DRIVER_Y6_PIN			PIN2

#define DRIVER_Y5_PART		GPIOD
#define DRIVER_Y5_PIN			PIN1

#define DRIVER_Y4_PART		GPIOD
#define DRIVER_Y4_PIN			PIN0

#define DRIVER_Y3_PART		GPIOC
#define DRIVER_Y3_PIN			PIN5

#define DRIVER_Y2_PART		GPIOC
#define DRIVER_Y2_PIN			PIN4

#define DRIVER_Y1_PART		GPIOC
#define DRIVER_Y1_PIN			PIN3

#endif

#if XSC  >0UL						//新视窗
#define DRIVER_Y10_PART		GPIOD	
#define DRIVER_Y10_PIN		PIN6

#define DRIVER_Y9_PART		GPIOD	
#define DRIVER_Y9_PIN			PIN5

#define DRIVER_Y8_PART		GPIOD
#define DRIVER_Y8_PIN			PIN4

#define DRIVER_Y7_PART		GPIOD
#define DRIVER_Y7_PIN			PIN3

#define DRIVER_Y6_PART		GPIOD
#define DRIVER_Y6_PIN			PIN2

#define DRIVER_Y5_PART		GPIOD
#define DRIVER_Y5_PIN			PIN1

#define DRIVER_Y4_PART		GPIOD
#define DRIVER_Y4_PIN			PIN0

#define DRIVER_Y3_PART		GPIOC
#define DRIVER_Y3_PIN			PIN5

#define DRIVER_Y2_PART		GPIOC
#define DRIVER_Y2_PIN			PIN4

#define DRIVER_Y1_PART		GPIOC
#define DRIVER_Y1_PIN			PIN3


#endif 


#if DEFAULT>0ul					//默认

#define DRIVER_Y10_PART		GPIOD	
#define DRIVER_Y10_PIN		PIN6

#define DRIVER_Y9_PART		GPIOD	
#define DRIVER_Y9_PIN			PIN5

#define DRIVER_Y8_PART		GPIOD
#define DRIVER_Y8_PIN			PIN4

#define DRIVER_Y7_PART		GPIOD
#define DRIVER_Y7_PIN			PIN3

#define DRIVER_Y6_PART		GPIOD
#define DRIVER_Y6_PIN			PIN2

#define DRIVER_Y5_PART		GPIOD
#define DRIVER_Y5_PIN			PIN1

#define DRIVER_Y4_PART		GPIOD
#define DRIVER_Y4_PIN			PIN0

#define DRIVER_Y3_PART		GPIOC
#define DRIVER_Y3_PIN			PIN5

#define DRIVER_Y2_PART		GPIOC
#define DRIVER_Y2_PIN			PIN4

#define DRIVER_Y1_PART		GPIOC
#define DRIVER_Y1_PIN			PIN3
#endif


#if REVERSE_ORDER >0ul  //倒序
#define DRIVER_Y10_PART		GPIOC	
#define DRIVER_Y10_PIN		PIN3

#define DRIVER_Y9_PART		GPIOC	
#define DRIVER_Y9_PIN			PIN4

#define DRIVER_Y8_PART		GPIOC
#define DRIVER_Y8_PIN			PIN5

#define DRIVER_Y7_PART		GPIOD
#define DRIVER_Y7_PIN			PIN0

#define DRIVER_Y6_PART		GPIOD
#define DRIVER_Y6_PIN			PIN1

#define DRIVER_Y5_PART		GPIOD
#define DRIVER_Y5_PIN			PIN2

#define DRIVER_Y4_PART		GPIOD
#define DRIVER_Y4_PIN			PIN3

#define DRIVER_Y3_PART		GPIOC
#define DRIVER_Y3_PIN			PIN4

#define DRIVER_Y2_PART		GPIOC
#define DRIVER_Y2_PIN			PIN5

#define DRIVER_Y1_PART	GPIOD
#define DRIVER_Y1_PIN		PIN6
#endif

/**  列引脚定义 **/


/**  反馈引脚定义 **/

#if  WM>0ul							 //微米

#define MOTOR_FB1_PART    GPIOA
#define MOTOR_FB1_PIN			PIN0

#define MOTOR_FB2_PART		GPIOB
#define MOTOR_FB2_PIN			PIN1

#define MOTOR_FB3_PART		GPIOE		
#define MOTOR_FB3_PIN			PIN5

#define MOTOR_FB4_PART		GPIOE
#define MOTOR_FB4_PIN			PIN4

#define MOTOR_FB5_PART		GPIOA	
#define MOTOR_FB5_PIN			PIN15	

#define MOTOR_FB6_PART		GPIOA
#define MOTOR_FB6_PIN			PIN14

#define MOTOR_FB7_PART		GPIOA	
#define MOTOR_FB7_PIN			PIN13

#define MOTOR_FB8_PART		GPIOA
#define MOTOR_FB8_PIN			PIN12

#define MOTOR_FB9_PART		GPIOC
#define MOTOR_FB9_PIN			PIN7

#define MOTOR_FB10_PART		GPIOC
#define MOTOR_FB10_PIN		PIN6

#endif

#if  XSC > 0ul					 //新视窗
#define MOTOR_FB1_PART    GPIOC
#define MOTOR_FB1_PIN			PIN6

#define MOTOR_FB2_PART		GPIOC
#define MOTOR_FB2_PIN			PIN7

#define MOTOR_FB3_PART		GPIOA		
#define MOTOR_FB3_PIN			PIN12

#define MOTOR_FB4_PART		GPIOA
#define MOTOR_FB4_PIN			PIN13

#define MOTOR_FB5_PART		GPIOA	
#define MOTOR_FB5_PIN			PIN14	

#define MOTOR_FB6_PART		GPIOA
#define MOTOR_FB6_PIN			PIN15

#define MOTOR_FB7_PART		GPIOE	
#define MOTOR_FB7_PIN			PIN4

#define MOTOR_FB8_PART		GPIOE
#define MOTOR_FB8_PIN			PIN5

#define MOTOR_FB9_PART		GPIOC
#define MOTOR_FB9_PIN			PIN1

#define MOTOR_FB10_PART		GPIOB
#define MOTOR_FB10_PIN		PIN5
#endif


#if  DEFAULT>0ul				 //默认

#define MOTOR_FB1_PART    GPIOB
#define MOTOR_FB1_PIN			PIN5

#define MOTOR_FB2_PART		GPIOB
#define MOTOR_FB2_PIN			PIN1

#define MOTOR_FB3_PART		GPIOE		
#define MOTOR_FB3_PIN			PIN5

#define MOTOR_FB4_PART		GPIOE
#define MOTOR_FB4_PIN			PIN4
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

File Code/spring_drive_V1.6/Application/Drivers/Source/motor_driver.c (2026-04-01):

#include "motor_driver.h"
#include "SEGGER_RTT.h"

/**电机忙标志**/
static uint8_t  load_stat = 0;
/**电机忙标志**/

/**位置反馈计数标志**/
static uint8_t  fb_count_Y1 =	0;
static uint8_t  fb_count_Y2 =	0;
static uint8_t  fb_count_Y3 =	0;
static uint8_t  fb_count_Y4 =	0;
static uint8_t  fb_count_Y5 =	0;
static uint8_t  fb_count_Y6 =	0;
static uint8_t  fb_count_Y7 =	0;
static uint8_t  fb_count_Y8 =	0;
static uint8_t  fb_count_Y9 =	0;
static uint8_t  fb_count_Y10 =0;
/**位置反馈计数标志**/
static uint8_t fb_exti_cnt =0;

static uint8_t current_num =0;

/**控制及反馈引脚表**/
static const struct  MotorDrive_TAB 
{
    MotorDrive_GPIO_PART* part_x;
    MotorDrive_GPIO_Pin pin_x;

    MotorDrive_GPIO_PART* part_y;
    MotorDrive_GPIO_Pin pin_y;

    MotorFB_GPIO_PART*  fb_part;
    MotorFB_GPIO_Pin   fb_pin;

} motorDrive_tab[11]=
{
    {0,0,0,0,0,0},//占个坑 好计算
    {DRIVER_X1_PIN_AND_PART,DRIVER_Y1_PIN_AND_PART, MOTOR_FB1_PIN_AND_PART},
    {DRIVER_X2_PIN_AND_PART,DRIVER_Y2_PIN_AND_PART, MOTOR_FB2_PIN_AND_PART},
    {DRIVER_X3_PIN_AND_PART,DRIVER_Y3_PIN_AND_PART, MOTOR_FB3_PIN_AND_PART},
    {DRIVER_X4_PIN_AND_PART,DRIVER_Y4_PIN_AND_PART, MOTOR_FB4_PIN_AND_PART},
    {DRIVER_X5_PIN_AND_PART,DRIVER_Y5_PIN_AND_PART, MOTOR_FB5_PIN_AND_PART},
    {DRIVER_X6_PIN_AND_PART,DRIVER_Y6_PIN_AND_PART, MOTOR_FB6_PIN_AND_PART},
    {DRIVER_X7_PIN_AND_PART,DRIVER_Y7_PIN_AND_PART, MOTOR_FB7_PIN_AND_PART},
    {DRIVER_X8_PIN_AND_PART,DRIVER_Y8_PIN_AND_PART, MOTOR_FB8_PIN_AND_PART},
    {DRIVER_X9_PIN_AND_PART,DRIVER_Y9_PIN_AND_PART, MOTOR_FB9_PIN_AND_PART},
    {DRIVER_X10_PIN_AND_PART,DRIVER_Y10_PIN_AND_PART, MOTOR_FB10_PIN_AND_PART}

};
/**控制及反馈引脚表**/


/***********本地调用**********/
static uint8_t current_channel_updata(uint8_t number);
static uint8_t get_x_num(uint8_t number);
static uint8_t get_y_num(uint8_t number);
static uint8_t check_xy(uint8_t x,uint8_t y);
static uint8_t check_ir(void);
static uint8_t check_motor(uint8_t x, uint8_t y);
static void motor_driver_io_init(void);
static void motor_fb_io_init(void);
static void motor_fb_exti_init(void);
/**********本地调用************/


/****************************************************************************************************************************************** 
* 函数名称: motor_init
* 功能说明: 初始化电机控制以及反馈引脚
* 输    入: void
* 输    出: void
* 注意事项: 外部调用
******************************************************************************************************************************************/
void motor_init(void)
{

    motor_driver_io_init();
    motor_fb_io_init();
    motor_fb_exti_init();

}

/****************************************************************************************************************************************** 
* 函数名称: motor_fb_exti_enable
* 功能说明: 使能位置反馈引脚中断
* 输    入: y 电机列 
* 输    出: 成功返回1 否则返回-1
* 注意事项: 外部调用
******************************************************************************************************************************************/
int motor_fb_exti_enable(uint8_t y)//开电机位置线中断
{
    if(y > 0x0A || y==0)return -1;

    EXTI_Open(motorDrive_tab[y].fb_part,motorDrive_tab[y].fb_pin);

    return 1;
}
/****************************************************************************************************************************************** 
* 函数名称: motor_fb_exti_disable
* 功能说明: 失能位置反馈引脚中断
* 输    入: y 电机列 
* 输    出: 成功返回1 否则返回-1
* 注意事项: 外部调用
******************************************************************************************************************************************/
int motor_fb_exti_disable(uint8_t y)//关点击位置线中断
{
    if(y > 10 || y==0)return -1;

    EXTI_Close(motorDrive_tab[y].fb_part,motorDrive_tab[y].fb_pin);

    return 1;
}

/****************************************************************************************************************************************** 
* 函数名称: fb_motor_on
* 功能说明: 有反馈电机转一圈
* 输    入: 
* 输    出: 
* 注意事项: 
******************************************************************************************************************************************/
int fb_motor_on(uint8_t number)	//电机旋转一圈
{
    uint8_t x =0;
    uint8_t y =0;
    uint8_t  err=0;
	
    err = current_channel_updata(number);
    if(err == 0xEE)return -1;
    
		x =	get_x_num(number);
    y = get_y_num(number);

    err = check_xy(x,y);
    if(err == 0xEE)return -1;
	
#if DEBUG >0ul
		SEGGER_RTT_printf(0, "channel is ture....\r\n");
#endif		
    if(vm_control.ir_flag == IR_CHECK_OPEN)
    {		
        err = check_ir();
        if(err == 0xEE)return -1;
				wait_ir_flag_set();		
			
				hw_timr_ir_init(vm_control.load_type);	
			
#if DEBUG > 0ul				
				SEGGER_RTT_printf(0, "Enable IR TIMER....\r\n");	
#endif					
			
        IR_EXTI_ENABLE();			 //打开红外引脚中断
			
#if DEBUG > 0ul
		SEGGER_RTT_printf(0, "Enable IR EXTI....\r\n");
#endif				
			
    }
    else if(vm_control.ir_flag == IR_CHECK_CLOSE)
    {
        IR_EXTI_DISABLE();
#if DEBUG >0ul
		SEGGER_RTT_printf(0, "Disable IR EXTI....\r\n");
#endif						
    }
    else
    {
        return -1; //这一步很重要
    }
		
		
		hw_timr_motor_init(vm_control.load_type);
		
#if ENABLE_WDT >0u		
		SEGGER_RTT_printf(0, "motor timer start....\r\n");
#endif
		

		err = check_motor(x,y);
    if(err == 0xEE)
    {
#if ENABLE_WDT >0u			
				SEGGER_RTT_printf(0, "motor error....\r\n");
#endif			
        return -1;
    }	

    if( load_status_get() == LOAD_IS_FREE)
    {				
        load_set_buys();
#if ENABLE_WDT >0u	
				SEGGER_RTT_printf(0, "motor outputting....\r\n");
#endif			
    }

    
		return 1;
}

/****************************************************************************************************************************************** 
* 函数名称: motor_off
* 功能说明: 
* 输    入: 
* 输    出: 
* 注意事项: 
******************************************************************************************************************************************/
int motor_off(uint8_t number)	//电机停止旋转
{
    uint8_t x =0;
    uint8_t y =0;
    uint8_t err=0;
	
    x =	get_x_num(number);
    y = get_y_num(number);

    err = check_xy(x,y);
    if(err == 0xEE)return -1;


    if( x>10 || y>10 || x==0 || y==0 )
    {
        return -1;
    }
    else
    {
        GPIO_ClrBit(motorDrive_tab[x].part_x,motorDrive_tab[x].pin_x);
        GPIO_SetBit(motorDrive_tab[y].part_y,motorDrive_tab[y].pin_y);	
        motor_fb_exti_disable(y);
    }

		load_free_buys();
    return 1;
}

/****************************************************************************************************************************************** 
* 函数名称: load_status_get
* 功能说明: 
* 输    入: 
* 输    出: 
* 注意事项: 
******************************************************************************************************************************************/
uint8_t load_status_get(void)
{				
			return load_stat;
}
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

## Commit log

2026-04-01 提交使用说明
2026-04-01 使用说明
